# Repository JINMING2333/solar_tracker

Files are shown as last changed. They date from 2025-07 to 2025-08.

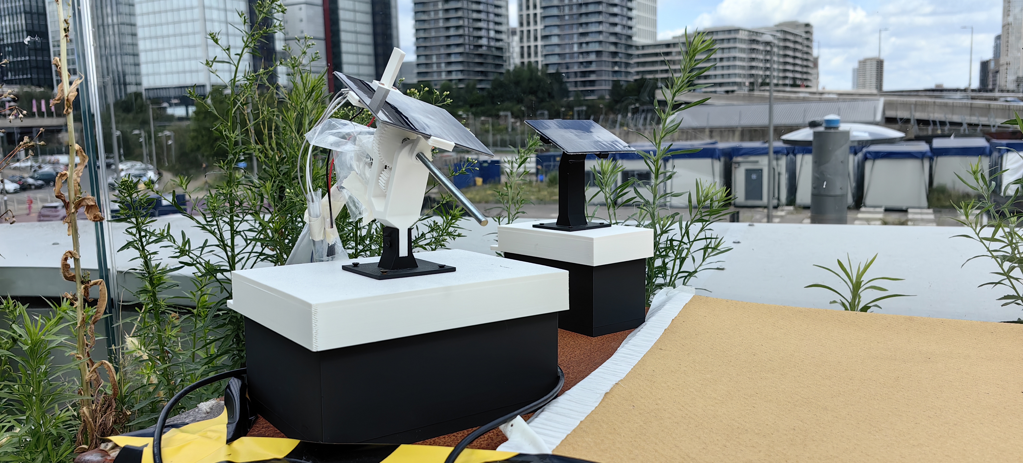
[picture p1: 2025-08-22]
IMG/outdoor_2.jpg

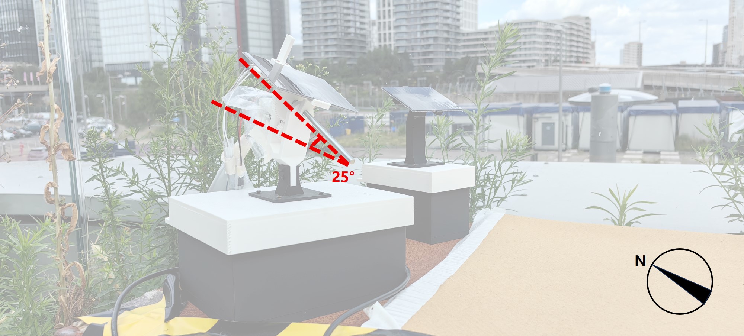
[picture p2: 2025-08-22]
IMG/south_25.jpg

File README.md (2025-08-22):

# ☀️ Low-Power Solar Tracking System for Remote Environmental Monitoring

This project presents a **cost-effective**, **energy-efficient**, and **autonomously powered** single-axis solar tracking system, designed to support **off-grid environmental sensor nodes** in outdoor deployments.

## 📌 Overview

The system leverages:
- A **single-axis tracking mechanism** driven by a DC motor with encoder feedback.
- **SunPosition astronomical algorithm** combined with LDR-based fine-tuning for dynamic solar angle adjustment.
- **Real-time energy monitoring** using INA219 sensors (solar panel input, logic circuit, and motor load).
- **LoRaWAN communication** via Arduino MKR WAN 1310, with real-time data upload to **The Things Network (TTN)**.
- **Low-power design** with deep sleep scheduling using a DS3231 RTC module.
- **Interactive visualization** using InfluxDB + Grafana on a Raspberry Pi backend.

## 📦 Hardware Components

| Component | Model / Type |
|---|---|
| MCU | Arduino MKR WAN 1310 |
| Solar Panel | 3W 6V Polycrystalline (145×145mm) |
| Battery | 3.7V 3300mAh 18650 Li-ion |
| Charging Module | Adafruit BQ24074 |
| Motor | N20 6V DC motor with encoder |
| INA219 Current Sensor | x3 (motor / logic / solar) |
| LDR Light Sensors | x2 |
| RTC | DS3231 |
| Voltage Regulator | Pololu S7V8F5 (5V output) |
| Enclosure | PLA / silicone sealed (3D printed)  |

## 🔧 Features

- ✅ **Single-axis rotation** covering ±90° azimuthal range.
- ✅ **Auto-homing on startup** using mechanical end-stop and encoder feedback.
- ✅ **Day/night detection** and dynamic sleep interval switching (10min daytime / 30min nighttime).
- ✅ **LoRa reconnect logic** for reliable long-term outdoor deployment.
- ✅ **Low-power design**: average sleep current < 12mA.
- ✅ **Field-proven**: 3 rounds of rooftop deployments with performance comparison against fixed panels.

## 📊 Results Summary

| Deployment Date | Weather | Tracking Gain | Energy Self-Sufficiency |
|---|---|---|---|
| July 1–4 | Mixed | ❌ (unstable)  | ❌ |
| July 28–30 | Cloudy | ❌ (fixed > tracking) | ❌ |
| Aug 14–17 | Sunny | ✅ (1.45× gain) | ✅ (>40 days est.) |

> 📍 All systems deployed at UCL One Pool Street rooftop garden, South-facing, 25° tilt angle.

## 📡 Data Visualization

- All power, current, voltage, and light intensity data are **uploaded to TTN**.
- Data are **subscribed via MQTT** on Raspberry Pi and stored in **InfluxDB**.
- **Grafana dashboards** display real-time tracking status and energy flow.

## 🚀 Repository Structure

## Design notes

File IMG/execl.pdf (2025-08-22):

Function
Overview

Core Libraries

Key Functions

Uses RTC to get real-time clock data and calculates the sun's azimuth based on geographic coordinates. The target angle is computed using a solar position algorithm. Then, LDR sensors are used for fine-tuning the final orientation to ensure accurate solar tracking.
RTClib.h → Reads real-time clock.
SunPosition.h → Computes solar azimuth using SPA (Solar Position Algorithm).
math.h → Provides basic math functions.
SunPosition() →Calculates the sunrise and sunset times of the day based on the time zone and geographic coordinates, thereby determining the full daytime interval.
computeLinearTgt() → Uses linear interpolation to map the current time's progress within the daytime interval to the motor's rotation range[ −90°，+90°], and outputs the target azimuth

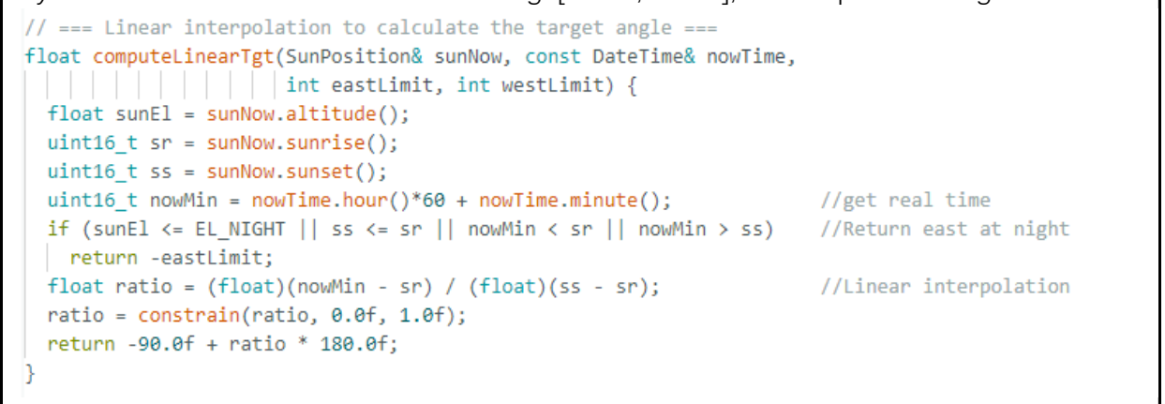
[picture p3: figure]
angle.

ldrDeltaSuggest() → Compares the readings from two LDR sensors (east and west) to determine the fine-tuning direction. Returns the absolute value of the difference and whether

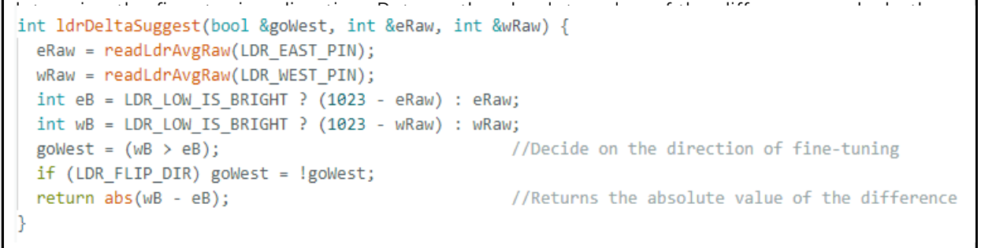
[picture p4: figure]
adjustment is needed.

loop for LDR() → Fine-tuning loop: within the set time, repeatedly calls ldrDeltaSuggest() to

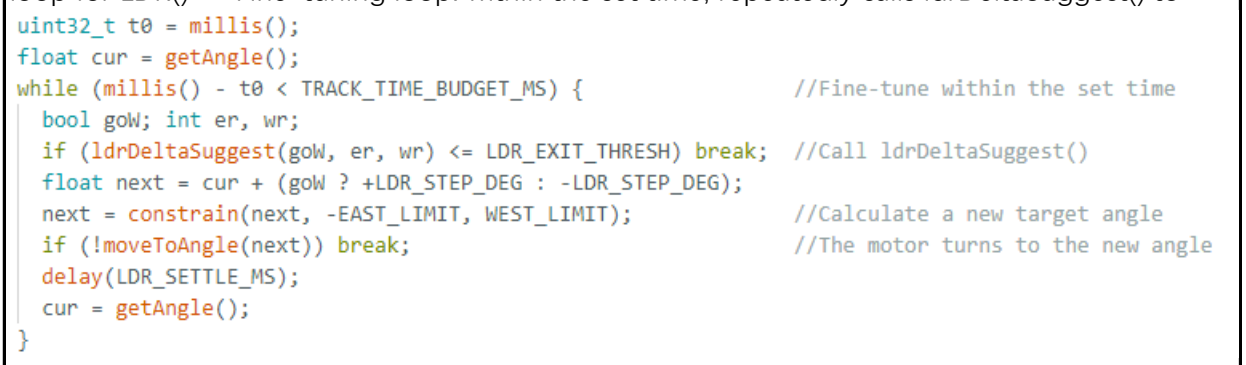
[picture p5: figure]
incrementally adjust the motor angle.

moveToAngle() →Moves the motor to the target angle.

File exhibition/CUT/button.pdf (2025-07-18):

– Press “Auto” button to simulate a 30 s “sunrise → sunset” and auto‐track one cycle.
– Remember: to run again, first toggle button off, then press on.

Note: Modes are mutually exclusive.
After you finish, please switch all buttons off.

# MODE 2· Manual-Track & Energy Comparison

– After exiting Mode 1, press “Manual” button to turn on the “little sun”.
– Slide control ←→ to move the “little sun”; the tracker follows.
– Two LED strips show fixed vs. tracked energy gain.
– Press button again to exit.
“Auto” Button | “Manual” Button | Slider

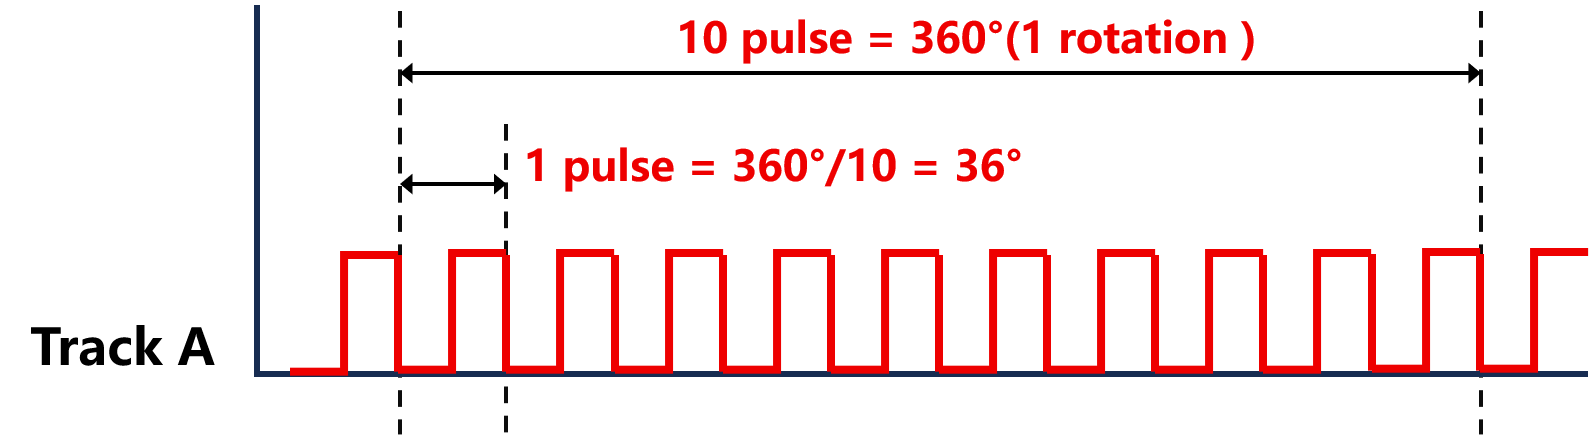
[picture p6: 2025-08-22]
IMG/encoder_principle.png

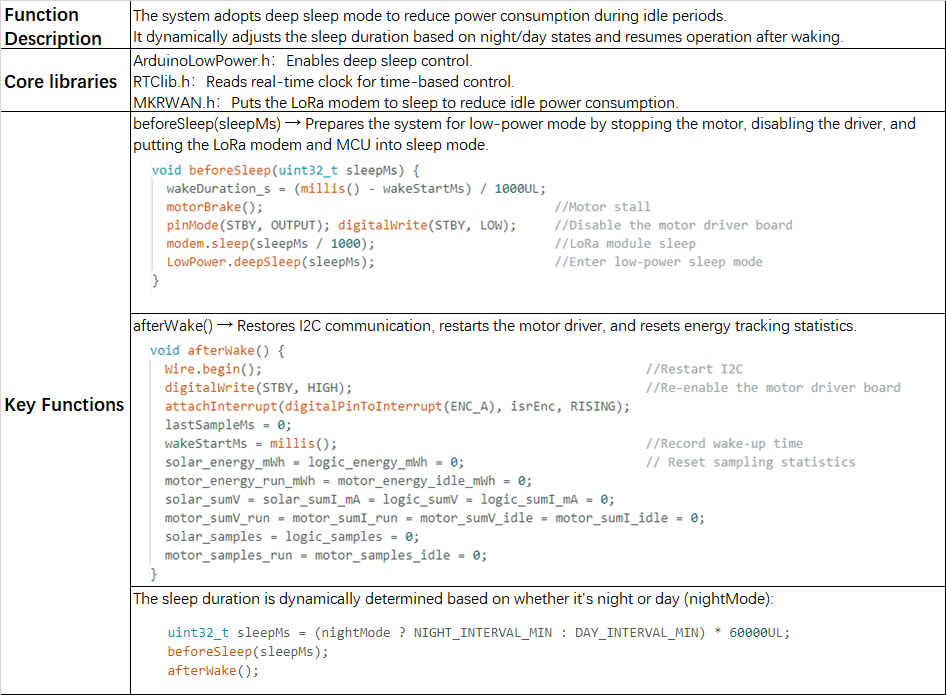
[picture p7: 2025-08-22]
IMG/execl (2).png

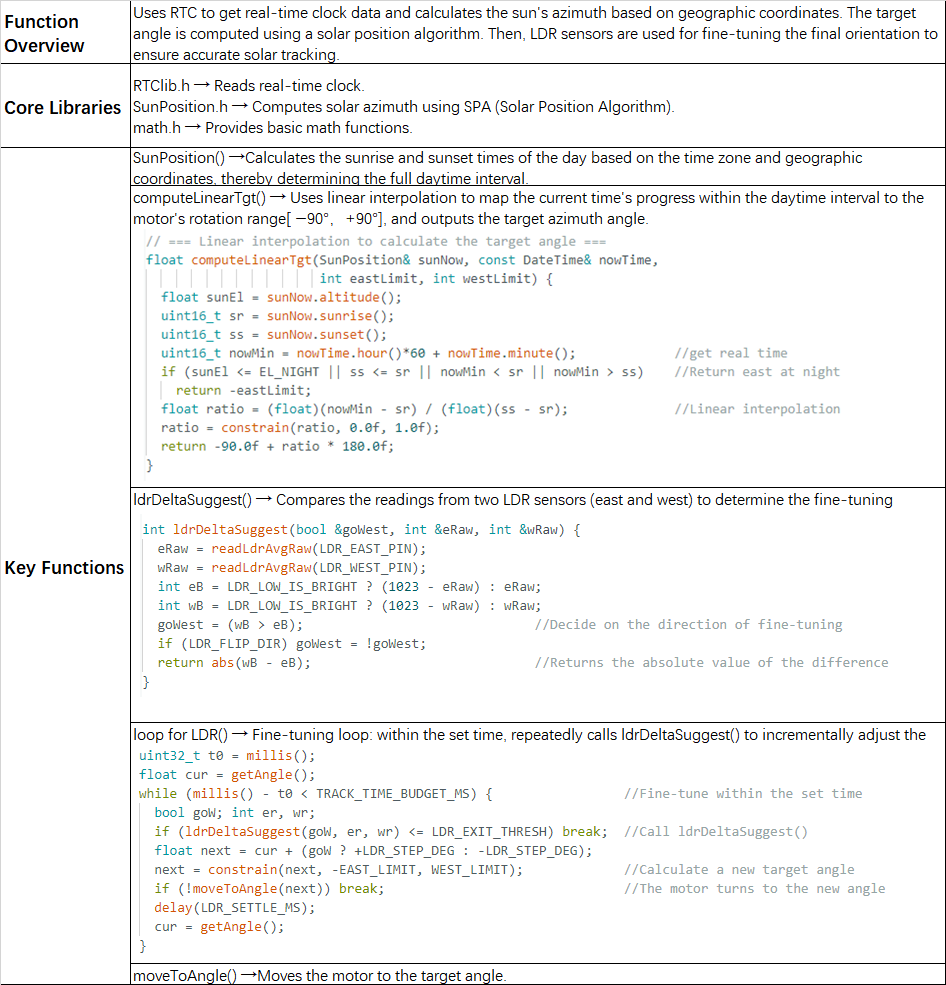
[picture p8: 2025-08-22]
IMG/execl.png

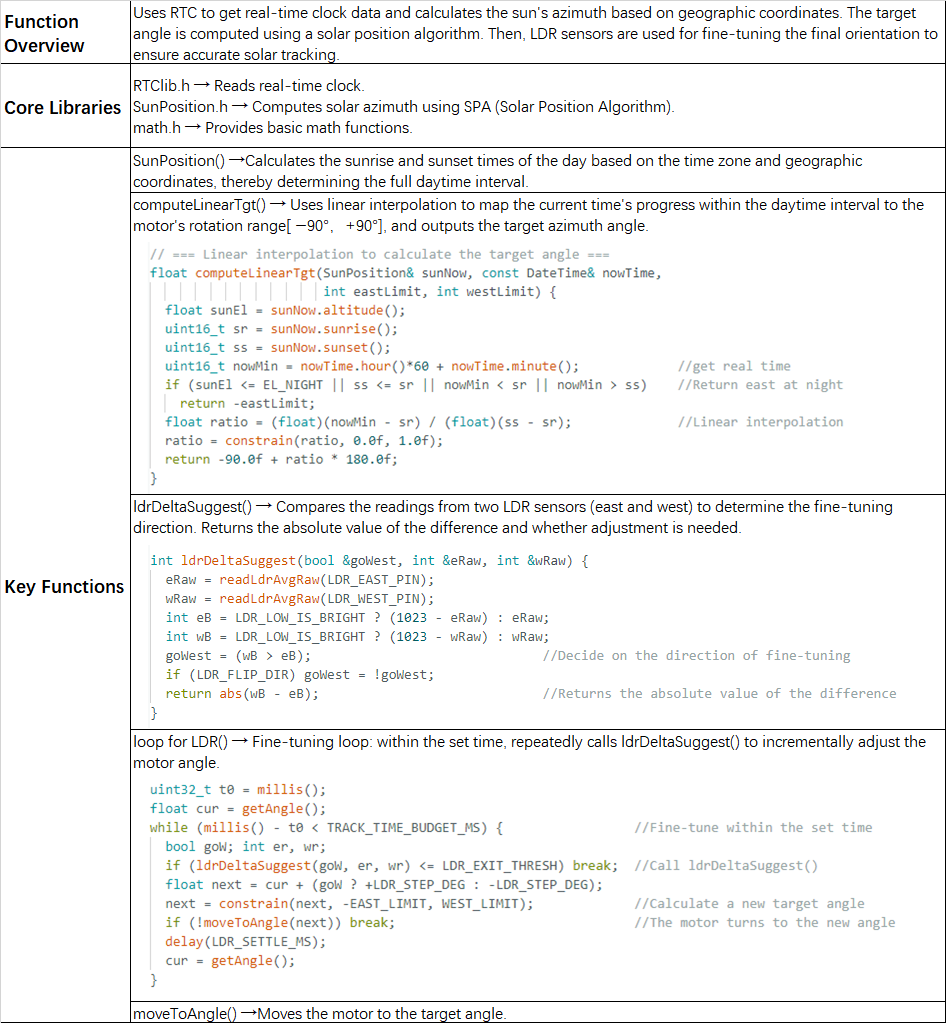
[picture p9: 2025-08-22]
IMG/execl (3).png

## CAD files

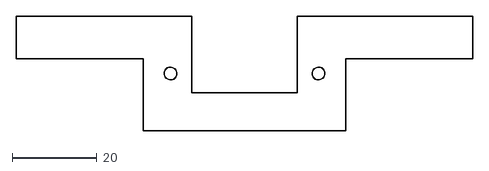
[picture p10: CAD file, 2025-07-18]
exhibition/CUT/motor.dxf
108.0 x 27.0

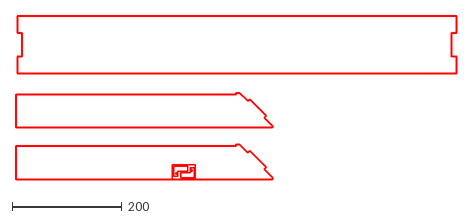
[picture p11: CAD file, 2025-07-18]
exhibition/CUT/SIDE.dxf
801.4 x 296.6

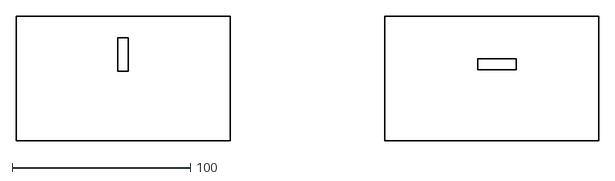
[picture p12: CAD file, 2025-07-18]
exhibition/CUT/OTHERS.dxf
326.5 x 70.0

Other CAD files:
model/model_01.skp
model/model_outdoor-0.skp
model/model_outdoor.skp
model/model_outdoor_2.skp
model/model_servo.skp

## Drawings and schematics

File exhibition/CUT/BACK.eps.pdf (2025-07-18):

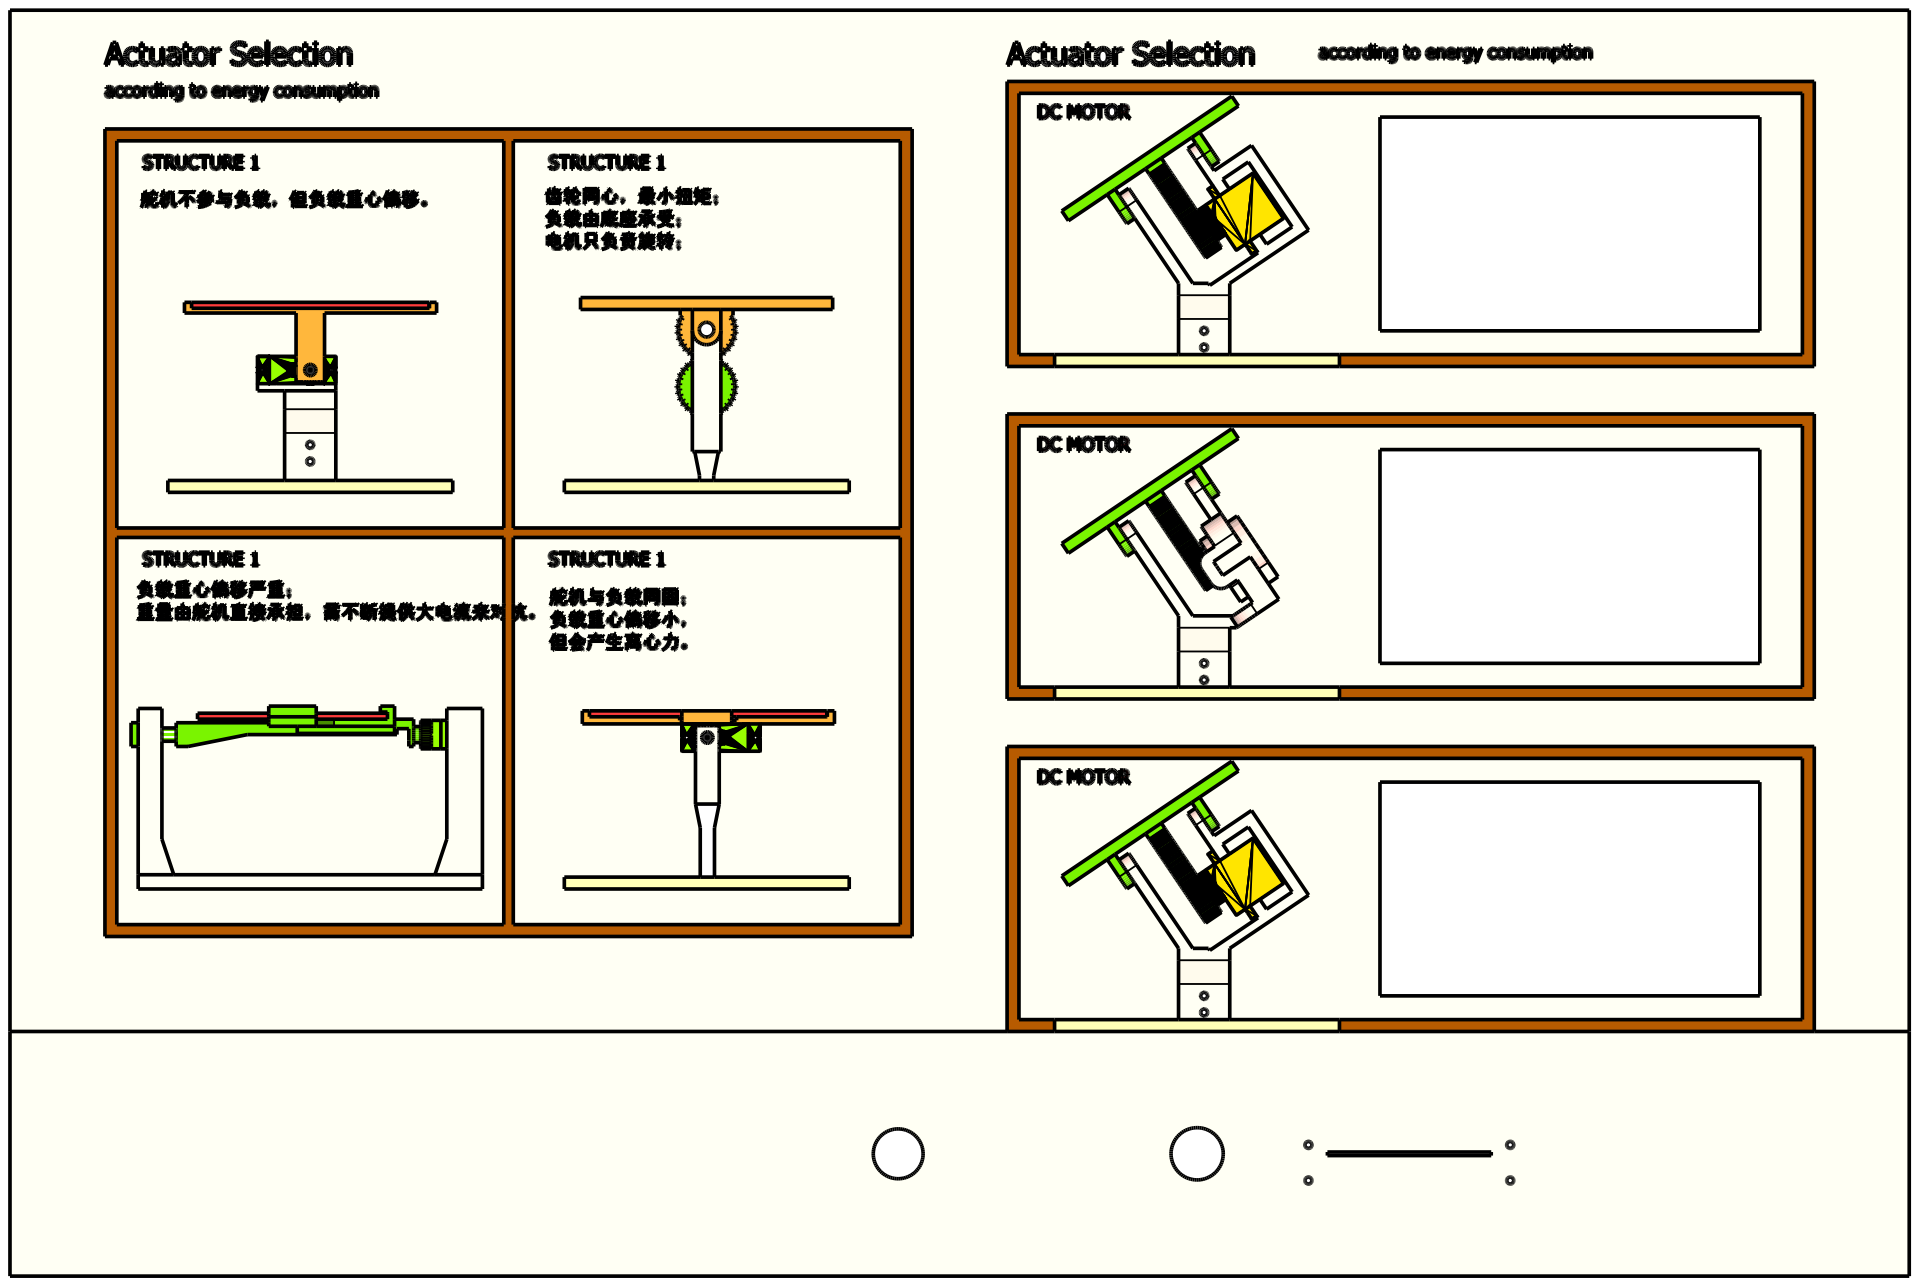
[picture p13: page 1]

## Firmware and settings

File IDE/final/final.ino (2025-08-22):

// === 依赖库 ===
#include <Wire.h>
#include <MKRWAN.h>
#include <RTClib.h>
#include <SunPosition.h>
#include <ArduinoLowPower.h>
#include <math.h>
#include <Adafruit_INA219.h>

// === 位置信息 ===
double LAT = 51.538593;
double LON = -0.009006;
int timeZone = 1;  // BST（伦敦夏令时）
RTC_DS3231 rtc;

// === LoRa 配置 ===
LoRaModem modem;
const char *appEui = "0000000000000000";
const char *appKey = "5DEF1848C136307477DC8E930E463F8F";
uint32_t lastJoinAttempt = 0;

// === 电机引脚与编码器 ===
const byte IN1 = 3, IN2 = 4, PWM = 5, STBY = 2;
const byte ENC_A = 6, ENC_B = 7;
const uint8_t PWM_DUTY = 180;
volatile long encCount = 0;
const float PULSE_PER_DEG = 4.7;
const int16_t EAST_LIMIT = 90;
const int16_t WEST_LIMIT = 90;
bool motorMoving = false;

// === LDR 参数 ===
const int LDR_EAST_PIN = A1, LDR_WEST_PIN = A0;
const bool LDR_LOW_IS_BRIGHT = true, LDR_FLIP_DIR = false;
const uint8_t LDR_SAMPLES = 4;
const float LDR_STEP_DEG = 2.0;
const uint16_t LDR_SETTLE_MS = 200;
const int LDR_EXIT_THRESH = 20;
const uint32_t TRACK_TIME_BUDGET_MS = 5000;

// === 日夜与唤醒间隔 ===
const float EL_NIGHT = 0.0, EL_DAY = 2.0;
const uint16_t DAY_INTERVAL_MIN = 10, NIGHT_INTERVAL_MIN = 30;
bool nightMode = false, homedEastTonight = false;

// === INA219 模块 ===
Adafruit_INA219 solarINA(0x40), logicINA(0x44), motorINA(0x41);

// === 电压电流能量统计 ===
float solar_energy_mWh = 0, logic_energy_mWh = 0;
float motor_energy_run_mWh = 0, motor_energy_idle_mWh = 0;
float solar_sumV = 0, solar_sumI_mA = 0;
float logic_sumV = 0, logic_sumI_mA = 0;
float motor_sumV_run = 0, motor_sumI_run = 0;
float motor_sumV_idle = 0, motor_sumI_idle = 0;
uint32_t solar_samples = 0, logic_samples = 0;
uint32_t motor_samples_run = 0, motor_samples_idle = 0;

// === 采样控制 ===
uint32_t lastSampleMs = 0;
const uint16_t SAMPLE_INTERVAL_MS = 50;
uint32_t wakeStartMs = 0;
uint16_t wakeDuration_s = 0;

// === 中断/角度相关 ===
void isrEnc() { encCount += digitalRead(ENC_B) ? +1 : -1; }
float getAngle() { return encCount / PULSE_PER_DEG; }

// === 电机控制函数 ===
void motorRun(bool fwd, uint8_t duty) {
  motorMoving = true;
  digitalWrite(IN1, fwd ? LOW : HIGH);
  digitalWrite(IN2, fwd ? HIGH : LOW);
  analogWrite(PWM, duty);
}

void motorBrake() {
  analogWrite(PWM, 0);
  digitalWrite(IN1, LOW);
  digitalWrite(IN2, LOW);
  motorMoving = false;
}

// === 角度移动控制（含采样）===
bool moveToAngle(float tgtDeg, uint32_t timeout = 8000) {
  tgtDeg = constrain(tgtDeg, -90, 90);
  long tgtPulse = lround(tgtDeg * PULSE_PER_DEG);
  bool fwd = (tgtPulse > encCount);
  motorRun(fwd, PWM_DUTY);
  uint32_t t0 = millis();
  long prev = encCount;

  while (fwd ? encCount < tgtPulse : encCount > tgtPulse) {
    uint32_t nowMs = millis();
    sampleSensors(nowMs);
    if (nowMs - t0 > timeout || (nowMs - t0 > 5000 && encCount == prev)) {
      motorBrake();
      return false;
    }
    prev = encCount;
  }

  motorBrake();
  encCount = constrain(encCount, -90 * PULSE_PER_DEG, +90 * PULSE_PER_DEG);
  return true;
}

void autoHoming() {
  Serial.println("🚩 Entering autoHoming()");
  const uint32_t timeout = 10000;
  const uint8_t duty = 100;
  long lastCount = encCount;
  uint32_t start = millis();
  
  motorMoving = true;  // ✅ 开始动作前，标记为运动
  motorRun(false, duty);  // 向东归零

  while (millis() - start < timeout) {
    delay(200);
    if (encCount == lastCount) break;  // 到机械限位
    lastCount = encCount;
  }

  motorBrake();
  motorMoving = false;  // ✅ 动作完成后，标记为静止
  encCount = -90 * PULSE_PER_DEG;
  Serial.println("✅ Homing complete.");
}

// === LDR 比较建议方向 ===
int readLdrAvgRaw(int pin, uint8_t n=LDR_SAMPLES) {
  long s = 0;
  for (uint8_t i = 0; i < n; i++) {
    s += analogRead(pin);
    delay(2);
  }
  return s / n;
}

int ldrDeltaSuggest(bool &goWest, int &eRaw, int &wRaw) {
  eRaw = readLdrAvgRaw(LDR_EAST_PIN);
  wRaw = readLdrAvgRaw(LDR_WEST_PIN);
  int eB = LDR_LOW_IS_BRIGHT ? (1023 - eRaw) : eRaw;
  int wB = LDR_LOW_IS_BRIGHT ? (1023 - wRaw) : wRaw;
  goWest = (wB > eB);                              //Decide on the direction of fine-tuning
  if (LDR_FLIP_DIR) goWest = !goWest;
  return abs(wB - eB);                             //Returns the absolute value of the difference
}

// === Linear interpolation to calculate the target angle ===
float computeLinearTgt(SunPosition& sunNow, const DateTime& nowTime,
                       int eastLimit, int westLimit) {
  float sunEl = sunNow.altitude();
  uint16_t sr = sunNow.sunrise();
  uint16_t ss = sunNow.sunset();
  uint16_t nowMin = nowTime.hour()*60 + nowTime.minute();             //get real time
  if (sunEl <= EL_NIGHT || ss <= sr || nowMin < sr || nowMin > ss)    //Return east at night
    return -eastLimit;
  float ratio = (float)(nowMin - sr) / (float)(ss - sr);              //Linear interpolation
  ratio = constrain(ratio, 0.0f, 1.0f);
  return -90.0f + ratio * 180.0f;
}

// === sampling ===
void sampleSensors(uint32_t nowMs) {
  if (lastSampleMs != 0 && nowMs - lastSampleMs < SAMPLE_INTERVAL_MS) return;
  lastSampleMs = nowMs;
  float vS = solarINA.getBusVoltage_V(), iS = solarINA.getCurrent_mA();
  float vL = logicINA.getBusVoltage_V(), iL = logicINA.getCurrent_mA();
  float vM = motorINA.getBusVoltage_V(), iM = motorINA.getCurrent_mA();

  if (vS >= 0 && iS >= 0) {
    solar_sumV += vS; solar_sumI_mA += iS;
    solar_samples++;
    solar_energy_mWh += (vS * iS) * (SAMPLE_INTERVAL_MS / 3600000.0f);
  }

  if (vL >= 0 && iL >= 0) {
    logic_sumV += vL; logic_sumI_mA += iL;
    logic_samples++;
    logic_energy_mWh += (vL * iL) * (SAMPLE_INTERVAL_MS / 3600000.0f);
  }

  if (vM >= 0 && iM >= 0) {
    if (motorMoving) {
      motor_sumV_run += vM; motor_sumI_run += iM;
      motor_samples_run++;
      motor_energy_run_mWh += (vM * iM) * (SAMPLE_INTERVAL_MS / 3600000.0f);
    } else {
      motor_sumV_idle += vM; motor_sumI_idle += iM;
      motor_samples_idle++;
      motor_energy_idle_mWh += (vM * iM) * (SAMPLE_INTERVAL_MS / 3600000.0f);
    }
  }
}


void beforeSleep(uint32_t sleepMs) {
  wakeDuration_s = (millis() - wakeStartMs) / 1000UL;
  motorBrake();                                       //Motor stall
  pinMode(STBY, OUTPUT); digitalWrite(STBY, LOW);     //Disable the motor driver board
  modem.sleep(sleepMs / 1000);                        //LoRa module sleep
  LowPower.deepSleep(sleepMs);                        //Enter low-power sleep mode
}

void afterWake() {
  Wire.begin();                                                   //Restart I2C
  digitalWrite(STBY, HIGH);                                       //Re-enable the motor driver board
  attachInterrupt(digitalPinToInterrupt(ENC_A), isrEnc, RISING);
  lastSampleMs = 0;
  wakeStartMs = millis();                                         //Record wake-up time
  solar_energy_mWh = logic_energy_mWh = 0;                        // Reset sampling statistics
  motor_energy_run_mWh = motor_energy_idle_mWh = 0;
  solar_sumV = solar_sumI_mA = logic_sumV = logic_sumI_mA = 0;
  motor_sumV_run = motor_sumI_run = motor_sumV_idle = motor_sumI_idle = 0;
  solar_samples = logic_samples = 0;
  motor_samples_run = motor_samples_idle = 0;
}

// === 启动 ===
void setup() {
  Serial.begin(115200); delay(300);
  pinMode(IN1, OUTPUT); pinMode(IN2, OUTPUT); pinMode(PWM, OUTPUT); pinMode(STBY, OUTPUT);
  pinMode(ENC_A, INPUT_PULLUP); pinMode(ENC_B, INPUT_PULLUP);
  digitalWrite(STBY, HIGH);
  attachInterrupt(digitalPinToInterrupt(ENC_A), isrEnc, RISING);

  Wire.begin(); rtc.begin();
  solarINA.begin(); logicINA.begin(); motorINA.begin();

  if (!modem.begin(EU868)) { Serial.println("❌ LoRa init failed"); while(1); }
  modem.setADR(true); modem.setPort(1);
  if (modem.joinOTAA(appEui, appKey)) Serial.println("✅ LoRa joined");
  else Serial.println("⚠️ LoRa join failed");

  autoHoming();
  afterWake();
}

// === 主循环 ===
void loop() {
  DateTime now = rtc.now();
  char buf[32];
  snprintf(buf, sizeof(buf), "⏰ RTC Time: %04d-%02d-%02d %02d:%02d:%02d",
          now.year(), now.month(), now.day(),
          now.hour(), now.minute(), now.second());
  Serial.println(buf);

  uint32_t tUTC = now.unixtime() - 3600UL;  // BST to UTC
  SunPosition sun(LAT, LON, tUTC, timeZone);
  float sunEl = sun.altitude();

  if (!nightMode && sunEl <= EL_NIGHT) {
    if (!homedEastTonight && getAngle() > -EAST_LIMIT + 0.5f)
      moveToAngle(-EAST_LIMIT);
    nightMode = true; homedEastTonight = true;
  }

  if (nightMode && sunEl >= EL_DAY) {
    nightMode = false; homedEastTonight = false;
  }

  float tgt = -EAST_LIMIT;
  if (!nightMode) {
    tgt = computeLinearTgt(sun, now, EAST_LIMIT, WEST_LIMIT);
    moveToAngle(tgt);

    uint32_t t0 = millis();
    float cur = getAngle();
    while (millis() - t0 < TRACK_TIME_BUDGET_MS) {                 //Fine-tune within the set time
      bool goW; int er, wr;
      if (ldrDeltaSuggest(goW, er, wr) <= LDR_EXIT_THRESH) break;  //Call ldrDeltaSuggest()
      float next = cur + (goW ? +LDR_STEP_DEG : -LDR_STEP_DEG);    
      next = constrain(next, -EAST_LIMIT, WEST_LIMIT);             //Calculate a new target angle
      if (!moveToAngle(next)) break;                               //The motor turns to the new angle
      delay(LDR_SETTLE_MS);
      cur = getAngle();
    }
  }

  uint32_t holdStart = millis();
  uint16_t holdMs = nightMode ? 500 : 2000;
  while (millis() - holdStart < holdMs) {
    sampleSensors(millis());
    delay(5);
  }

  // 构建并发送 payload（略，为节省长度，可继续补全）
  if (!modem.connected()) {
    if (millis() - lastJoinAttempt > 300000UL) {
      if (modem.joinOTAA(appEui, appKey)) Serial.println("✅ Rejoined");
      else Serial.println("❌ Rejoin failed");
      lastJoinAttempt = millis();
    }
  } else {
    int16_t cur_x10 = (int16_t)lround(getAngle() * 10.0f);
    int16_t tgt_x10 = (int16_t)lround(tgt * 10.0f);
    uint16_t ldrEast = (uint16_t)readLdrAvgRaw(LDR_EAST_PIN);
    uint16_t ldrWest = (uint16_t)readLdrAvgRaw(LDR_WEST_PIN);
    uint16_t wake_s = (millis() - wakeStartMs) / 1000UL;

    float Vm_logic = logic_samples ? (logic_sumV / logic_samples) : 0.0f;
    float Im_logic = logic_samples ? (logic_sumI_mA / logic_samples) : 0.0f;
    float Vm_motor_idle = motor_samples_idle ? (motor_sumV_idle / motor_samples_idle) : 0.0f;
    float Im_motor_idle = motor_samples_idle ? (motor_sumI_idle / motor_samples_idle) : 0.0f;
    float Vm_motor_run = motor_samples_run ? (motor_sumV_run / motor_samples_run) : 0.0f;
    float Im_motor_run = motor_samples_run ? (motor_sumI_run / motor_samples_run) : 0.0f;
    float Vm_solar = solar_samples ? (solar_sumV / solar_samples) : 0.0f;
    float Im_solar = solar_samples ? (solar_sumI_mA / solar_samples) : 0.0f;

    uint16_t E_logic_x100 = (uint16_t)lround(max(0.0f, logic_energy_mWh) * 100.0f);
    uint16_t E_motor_idle_x100 = (uint16_t)lround(max(0.0f, motor_energy_idle_mWh) * 100.0f);
    uint16_t E_motor_run_x100 = (uint16_t)lround(max(0.0f, motor_energy_run_mWh) * 100.0f);
    uint16_t E_solar_x100 = (uint16_t)lround(max(0.0f, solar_energy_mWh) * 100.0f);
    uint16_t Vm_logic_x100 = (uint16_t)lround(max(0.0f, Vm_logic) * 100.0f);
    uint16_t Im_logic_x100 = (uint16_t)lround(max(0.0f, Im_logic) * 100.0f);
    uint16_t Vm_motor_idle_x100 = (uint16_t)lround(max(0.0f, Vm_motor_idle) * 100.0f);
    uint16_t Im_motor_idle_x100 = (uint16_t)lround(max(0.0f, Im_motor_idle) * 100.0f);
    uint16_t Vm_motor_run_x100 = (uint16_t)lround(max(0.0f, Vm_motor_run) * 100.0f);
    uint16_t Im_motor_run_x100 = (uint16_t)lround(max(0.0f, Im_motor_run) * 100.0f);
    uint16_t Vm_solar_x100 = (uint16_t)lround(max(0.0f, Vm_solar) * 100.0f);
    uint16_t Im_solar_x100 = (uint16_t)lround(max(0.0f, Im_solar) * 100.0f);

    uint8_t payload[36]; int i = 0;
    auto put16 = [&](uint16_t v) { payload[i++] = v & 0xFF; payload[i++] = v >> 8; };

    put16(cur_x10);           // 当前角度
    put16(tgt_x10);           // 目标角度
    put16(ldrEast);           // LDR东
    put16(ldrWest);           // LDR西
    put16(wake_s);            // 唤醒时间（秒）
    put16(E_logic_x100);      // 逻辑电路消耗
    put16(E_motor_idle_x100); // 电机静止消耗
    put16(E_motor_run_x100);  // 电机运动消耗
    put16(E_solar_x100);      // 太阳能吸收
    put16(Vm_logic_x100);     // 逻辑电压
    put16(Im_logic_x100);     // 逻辑电流
    put16(Vm_motor_idle_x100);// 电机静止电压
    put16(Im_motor_idle_x100);// 电机静止电流
    put16(Vm_motor_run_x100); // 电机运动电压
    put16(Im_motor_run_x100); // 电机运动电流
    put16(Vm_solar_x100);     // 太阳能电压
    put16(Im_solar_x100);     // 太阳能电流

    modem.beginPacket();
    modem.write(payload, sizeof(payload));
    int res = modem.endPacket(false);
    Serial.println(res == 0 ? "📡 LoRa OK" : "📡 LoRa FAIL");
  }

  uint32_t sleepMs = (nightMode ? NIGHT_INTERVAL_MIN : DAY_INTERVAL_MIN) * 60000UL;
  beforeSleep(sleepMs);
  afterWake();
}

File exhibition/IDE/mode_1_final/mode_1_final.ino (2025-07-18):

// === 非阻塞模式一：步进电机与直流电机同步运行并归位 ===
#include <AccelStepper.h>

// 步进电机设置（28BYJ-48）
const int stepsPerRevolution = 2048;
AccelStepper stepper(AccelStepper::FULL4WIRE, 8, 10, 9, 11);

// 直流电机控制引脚（TB6612）
const int PWMA = 5;
const int AIN1 = 7;
const int AIN2 = 4;
const int STBY = 6;

// 模式按钮（船型按钮）
const int mode1ButtonPin = 12;

// 状态控制
bool mode1Requested = false;
bool mode1Running = false;
bool mode1Finished = true;
unsigned long lastDebounceTime = 0;
const unsigned long debounceDelay = 50;
bool lastButtonState = HIGH;
bool currentButtonState = HIGH;

// 步进电机状态
long stepperTarget = 0;
bool stepperForward = true;
unsigned long stepperStartTime = 0;
bool stepperHoldBeforeReturn = false;
unsigned long stepperHoldStartTime = 0;
const unsigned long stepperHoldDelay = 3000;  // 3秒延迟

// 直流电机状态（缓慢前进+快速回转）
const int DC_STEP_DELAY = 150;
const int DC_STEP_WAIT = 1516;
const int DC_NUM_STEPS = 12;
int dcMotorStep = 0;  // 0=停止，1=缓慢前进，2=等待回转，3=快速回转
unsigned long dcLastStepTime = 0;
int dcCurrentStep = 0;
const int PWM_VALUE = 120;

unsigned long dcReturnTriggerTime = 0;
bool dcReadyToReturn = false;

void setup() {
  Serial.begin(9600);

  pinMode(mode1ButtonPin, INPUT_PULLUP);

  pinMode(PWMA, OUTPUT);
  pinMode(AIN1, OUTPUT);
  pinMode(AIN2, OUTPUT);
  pinMode(STBY, OUTPUT);
  digitalWrite(STBY, HIGH);

  stepper.setMaxSpeed(50);
  stepper.setAcceleration(200);
  stepper.moveTo(0);

  Serial.println("等待模式一按钮...");
}

void loop() {
  // 按钮防抖逻辑
  bool reading = digitalRead(mode1ButtonPin);
  if (reading != lastButtonState) {
    lastDebounceTime = millis();
  }
  if ((millis() - lastDebounceTime) > debounceDelay) {
    if (reading != currentButtonState) {
      currentButtonState = reading;
      if (currentButtonState == LOW) {
        mode1Requested = true;
        Serial.println("→ 模式一请求开启");
      } else {
        mode1Requested = false;
        Serial.println("← 模式一请求关闭");
      }
    }
  }
  lastButtonState = reading;

  // 启动模式一
  if (mode1Requested && !mode1Running) {
    mode1Running = true;
    mode1Finished = false;
    stepperForward = true;
    stepper.setMaxSpeed(50);
    stepper.moveTo(-stepsPerRevolution / 2);
    stepperStartTime = millis();
    dcMotorStep = 0;
    dcCurrentStep = 0;
    dcReadyToReturn = false;
    stepperHoldBeforeReturn = false;
    Serial.println("→ 步进电机开始缓慢旋转 180°");
  }

  // 步进电机运行逻辑
  if (mode1Running) {
    stepper.run();

    // 启动直流电机（延迟3秒）
    if (stepperForward && dcMotorStep == 0 && millis() - stepperStartTime >= 3000) {
      dcMotorStep = 1;
      dcLastStepTime = millis();
      dcCurrentStep = 0;
      Serial.println("→ 直流电机延迟后开始缓慢前进");
    }

    // 步进电机达到目标后，延迟一段时间再回转
    if (stepper.distanceToGo() == 0) {
      if (stepperForward && !stepperHoldBeforeReturn) {
        stepperHoldBeforeReturn = true;
        stepperHoldStartTime = millis();
        Serial.println("⏸ 步进电机已达 180°，等待 3 秒再回转...");
      }
      else if (!stepperForward && !dcReadyToReturn) {
        dcReadyToReturn = true;
        dcReturnTriggerTime = millis();
        Serial.println("✔ 步进电机归位，准备直流电机回转");
      }
    }

    // 超过等待时间后回转步进电机
    if (stepperHoldBeforeReturn && millis() - stepperHoldStartTime >= stepperHoldDelay) {
      stepperForward = false;
      stepper.setMaxSpeed(600);
      stepper.moveTo(0);
      stepperHoldBeforeReturn = false;
      Serial.println("← 步进电机快速回到 0°");
    }
  }

  // 直流电机缓慢前进控制
  if (dcMotorStep == 1 && millis() - dcLastStepTime >= DC_STEP_WAIT && dcCurrentStep < DC_NUM_STEPS) {
    digitalWrite(AIN1, HIGH);
    digitalWrite(AIN2, LOW);
    analogWrite(PWMA, PWM_VALUE);
    delay(DC_STEP_DELAY);
    analogWrite(PWMA, 0);
    dcLastStepTime = millis();
    dcCurrentStep++;
    Serial.print("直流电机步数：");
    Serial.println(dcCurrentStep);

    if (dcCurrentStep >= DC_NUM_STEPS) {
      dcMotorStep = 2;
      Serial.println("→ 直流电机等待回转");
    }
  }

  // 步进归位后延迟 1 秒再回转直流电机
  if (dcReadyToReturn && millis() - dcReturnTriggerTime >= 1000 && dcMotorStep == 2) {
    dcMotorStep = 3;
    dcLastStepTime = millis();
    digitalWrite(AIN1, LOW);
    digitalWrite(AIN2, HIGH);
    analogWrite(PWMA, PWM_VALUE);
    Serial.println("← 直流电机快速归位中...");
  }

  // 停止直流电机归位后
  if (dcMotorStep == 3 && millis() - dcLastStepTime >= 1800) {
    analogWrite(PWMA, 0);
    digitalWrite(AIN1, LOW);
    digitalWrite(AIN2, LOW);
    dcMotorStep = 0;
    dcReadyToReturn = false;
    Serial.println("✔ 直流电机已归位");

    // 完整周期结束
    mode1Running = false;
    mode1Finished = true;
    Serial.println("✅ 模式一周期完成");
    delay(3000);
  }

  // 如果按钮断开 + 完成，确保停机并释放步进电机
  if (!mode1Requested && mode1Finished) {
    analogWrite(PWMA, 0);
    digitalWrite(AIN1, LOW);
    digitalWrite(AIN2, LOW);
    stepper.stop();
    stepper.moveTo(0);
    for (int pin = 8; pin <= 11; pin++) {
      digitalWrite(pin, LOW);
    }
  }
}

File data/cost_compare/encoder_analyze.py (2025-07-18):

import pandas as pd
import numpy as np
import matplotlib.pyplot as plt
from scipy.signal import find_peaks

# ───────────────────── 参数区 ─────────────────────
CSV_PATH = "DC_encoder_100ms_01.csv"
STEP_DEGREE = 12
TOLERANCE = 1.0
PEAK_HEIGHT_THRESHOLD = 20  # mW 以上才认为是“有功率峰”
# ────────────────────────────────────────────────

# 1. 读取 CSV 数据
df = pd.read_csv(CSV_PATH, names=["ms", "deg", "V", "I", "P"], skiprows=1)
df["t_s"] = df["ms"] * 1e-3  # ms → s
df["P_W"] = df["P"] * 1e-3   # mW → W

# 2. 识别周期区间（第一次 >1° 到最后一次 <1°）
start_idx = df.index[df["deg"] > 1.0][0]
end_idx = df.index[::-1][df["deg"][::-1] < 1.0][0]
df_cycle = df.loc[start_idx:end_idx].reset_index(drop=True)

# 3. 寻找功率峰位置
peaks, _ = find_peaks(df_cycle["P"], height=PEAK_HEIGHT_THRESHOLD)

# 4. 对每个功率峰找前面的角度变化点（起始）
change_points = []
last_angle = df_cycle.at[0, "deg"]
for i in range(1, len(df_cycle)):
    current_angle = df_cycle.at[i, "deg"]
    if abs(current_angle - last_angle) >= TOLERANCE:
        change_points.append(i)
    last_angle = current_angle

# 5. 为每个峰配对角度点（向前找最近的变化点）
ticks_t = []
ticks_lbl = []
used_angles = set()
for p in peaks:
    # 找变化点中最靠近当前峰值前的位置
    candidates = [cp for cp in change_points if cp < p]
    if not candidates:
        continue
    idx = candidates[-1]
    t = df_cycle.at[idx, "t_s"]
    angle = df_cycle.at[idx, "deg"]
    rounded_angle = int(round(angle / STEP_DEGREE) * STEP_DEGREE) % 360
    # 防止重复标注
    if rounded_angle in used_angles:
        continue
    used_angles.add(rounded_angle)
    ticks_t.append(t)
    ticks_lbl.append(f"{rounded_angle}°")

# 6. 计算能量（单位：mWh）
from numpy import trapz
energy_mWh = trapz(df_cycle["P_W"], df_cycle["t_s"]) * (1000 / 3600)

# 7. 绘图
plt.figure(figsize=(12,5))
plt.plot(df_cycle["t_s"], df_cycle["P"], 'r-', linewidth=1, label="Power (mW)")

# 垂直线和角度文字
for t, lbl in zip(ticks_t, ticks_lbl):
    plt.axvline(t, color="blue", linestyle="--", linewidth=0.6)
    plt.text(t, plt.ylim()[1]*1.01, lbl, ha="center", va="bottom", fontsize=8)

plt.title(f"Power Consumption_50ms (Energy = {energy_mWh:.3f} mWh)", pad=25)
plt.xlabel("Time (s)")
plt.ylabel("Power (mW)")
plt.legend(loc='lower left', bbox_to_anchor=(1.01, 0.0), borderaxespad=0.)
plt.grid(True, linestyle="--", color='gray', alpha=0.3)

# 去边框
ax = plt.gca()
ax.spines['top'].set_visible(False)
ax.spines['right'].set_visible(False)

plt.tight_layout(rect=[0, 0, 0.85, 1])
plt.show()

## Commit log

2025-07-18 past 3 month
    [DC_encoder_01.csv, DC_encoder_02.csv, DC_encoder_03.csv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]
2025-08-22 all the things
    [energy_cost.fzz, execl.xlsx, fixed.fzz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]
